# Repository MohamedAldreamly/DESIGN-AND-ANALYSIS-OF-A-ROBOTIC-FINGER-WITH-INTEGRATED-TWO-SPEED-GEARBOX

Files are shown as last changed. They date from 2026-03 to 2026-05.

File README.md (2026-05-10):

# Robotic Finger with Two-Speed Gearbox

## Overview
This project presents the design and analysis of a robotic finger actuated by a compact two-speed gearbox. The system combines mechanical simplicity with efficient motion transmission by using direct coupling instead of traditional tendon-driven mechanisms.

The finger motion is achieved using a dual four-bar linkage system that ensures coordinated movement of the phalanges.

---

## Key Features
- Two-speed gearbox (Speed Mode & Force Mode)
- Direct mechanical coupling (no tendons required)
- Coordinated motion using four-bar linkage mechanisms
- Compact and efficient mechanical design
- Designed for educational and experimental applications

---

## System Description
The system consists of two main subsystems:

### 1. Gearbox
- Multi-stage spur gear system
- Two operating modes:
  - Speed Mode → fast motion
  - Force Mode → high torque output
- Dog clutch mechanism for switching between modes

### 2. Finger Mechanism
- Three phalanges connected by revolute joints
- Motion coordination achieved using two coupled four-bar linkages
- Direct connection between output shaft and first phalanx

---

## Design Process
The project was developed through the following steps:

1. Kinematic analysis of finger motion  
2. Four-bar linkage synthesis  
3. Torque estimation and gearbox design  
4. Gear selection and force calculations  
5. Shaft design (bending + torsion)  
6. CAD modeling using SolidWorks  
7. Motion simulation  
8. Structural validation using FEA  

---

## Analysis & Validation
- Analytical calculations for gears and shafts  
- Finite Element Analysis (FEA) for:
  - Output shaft  
  - Gear teeth  
  - Dog clutch  
- Validation of stress distribution and critical regions  

---

## Key Results
- Output torque achieved: ≈ 1.94 N·m  
- Smooth and coordinated finger motion  
- Good agreement between analytical and FEA results  
- Critical stress concentrations identified and analyzed  

---

## Limitations
- Stress concentration at shaft shoulders  
- Gear tooth root is the most critical region  
- Dog clutch engagement may introduce shock loads  
- No fatigue life analysis (future work)  

---

## Future Improvements
- Fatigue analysis under cyclic loading  
- Optimization of shaft geometry (fillet radius)  
- Improved clutch engagement mechanism  
- Prototype manufacturing and testing  

---

## Tools Used
- SolidWorks (CAD & Motion Analysis)  
- ANSYS (Finite Element Analysis)  
- Engineering calculations (analytical design)  

---

## Author
Mohamed Ayman Aldreamly  
Mechatronics Engineering Student  

---

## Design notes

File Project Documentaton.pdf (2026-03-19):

# DESIGN AND ANALYSIS OF A ROBOTIC FINGER WITH INTEGRATED TWO-SPEED GEARBOX

# Prepared by: Mohamed Ayman Aldreamly

## Courses: Mechanical Design Project Theory of Machine Kinematics

## Supervisor:

me

Alazhar University
Faculty of Engineering
Department of Mechatronics Engineering

March 2026

## Contents

- PROJECT OBJECTIVES AND PLANNING

- Gearbox–Finger Mechanical Coupling
- CAD Design and Motion Analysis
- Gearbox CAD Design
- Finite Element Analysis

8.2 FEA Results and Discussion of the Output Shaft under Combined Torsion and Bending ..56

- Failure Modes Analysis
- Conclusion

# - PROJECT OBJECTIVES AND PLANNING

## 1.1.1 Objectives and Constraints

The objective of this project is to design and analyze a robotic finger mechanism capable of producing coordinated finger flexion using a compact mechanical transmission system.

The robotic finger consists of three rigid phalanges connected through revolute joints. The motion of the finger is generated by a motor and transmitted through a compact gearbox integrated at the base of the finger.

Unlike tendon-driven robotic fingers, the actuation in this design is achieved through direct mechanical coupling between the gearbox output shaft and the first phalanx. The output shaft is oriented perpendicular to the first phalanx and connected using a mechanical screw joint.

The coordinated motion of the remaining phalanges is achieved using two coupled four-bar linkage mechanisms.

The design therefore integrates two main subsystems:

- A two-speed gearbox that provides different torque and speed operating modes.
- A four-bar linkage mechanism that coordinates the motion of the three phalanges.

The main design constraints are:

- Compact mechanical structure suitable for a robotic finger base.
- Smooth coordinated motion between phalanges.
- Sufficient output torque to flex the finger.
- Clear mechanical architecture suitable for educational demonstration.

## 1.1.2 Planning

The project development followed a systematic mechanical design approach consisting of several stages.

The first stage involved defining the motion requirements of the robotic finger and determining representative finger configurations.
The second stage focused on synthesizing a four-bar linkage mechanism capable of reproducing the desired motion of the finger joints.
The third stage involved estimating the torque requirements needed to move the finger mechanism.
The fourth stage consisted of designing a compact gearbox capable of providing two operating modes: high speed motion and high torque operation.
Finally, the gearbox output shaft was integrated directly with the first phalanx using a rigid mechanical connection to transmit rotation to the finger mechanism.

## 1.2 PRELIMINARY DESIGN

The robotic finger system integrates a gearbox actuator with a mechanical linkage mechanism.

The main structural components of the system are:

- Three rigid phalanges
- Revolute joints connecting the phalanges
- Two four-bar linkage mechanisms
- A compact two-speed gearbox
- A direct mechanical connection between the gearbox output shaft and the first phalanx

The gearbox is mounted at the base of the finger, and its output shaft is oriented perpendicular to the first phalanx.

The shaft is rigidly connected to the first phalanx using a screw connection. When the gearbox output shaft rotates, the first phalanx rotates around its base joint.

The motion of the first phalanx drives the four-bar linkage system, which in turn produces coordinated motion of the second and third phalanges.

This configuration simplifies the mechanical architecture and allows the robotic finger to be driven using a single actuator.

## 1.3 PHALANX ANALYSIS

The robotic finger consists of three rigid segments representing the phalanges.

Their lengths are:

Phalanx 1 = 50 mm
Phalanx 2 = 30 mm
Phalanx 3 = 20 mm

The motion of the finger is described by the rotation angles of the three phalanges relative to the base.

Three key configurations were defined to represent the range of motion of the finger:

Case 1 – extended finger
Case 2 – intermediate flexion
Case 3 – highly flexed finger

The position of the finger joints was calculated using planar kinematic relations.

The coordinates of the PIP joint are given by

x₁ = L₁ cos θ₁
y₁ = L₁ sin θ₁

The DIP joint coordinates depend on the cumulative rotation of the first two phalanges.

The fingertip coordinates depend on the cumulative rotation of all three phalanges.

These calculations define the motion trajectory of the finger and are used as input for the four-bar linkage synthesis.

## 1.4 PHALANX ANGLES

## 1.4.1 Defining Angles

To analyze the motion of the robotic finger, three rotational angles were defined corresponding to the rotation of each phalanx relative to its preceding segment.

These angles describe the configuration of the finger and determine the position of the joints during motion.

The angles used in the analysis are:

- θ1 : rotation of Phalanx 1 relative to the base joint
- θ2 : rotation of Phalanx 2 relative to Phalanx 1
- θ3 : rotation of Phalanx 3 relative to Phalanx 2

The cumulative angles used in the kinematic calculations are defined as:

α2 = θ1 + θ2
α3 = θ1 + θ2 + θ3

These angles determine the orientation of each link when calculating the joint positions in the planar coordinate system.

## 1.4.2 Measured Angles

Three reference finger configurations were selected to represent the full motion range of the robotic finger.

These configurations correspond to:

1. Extended finger position
2. Intermediate flexion
3. Highly flexed finger

The measured angles for each configuration are:

Configuration | θ1 θ2 θ3
Case 1 (Extended) | −3° 45° 27°
Case 2 (Intermediate) 39° 71° 43° Case 3 (Flexed) 77° 83° 50°

These values were used as the design targets for the linkage synthesis process.

## 1.4.3 Angles Achieved

After designing the four-bar linkage systems, the mechanism was able to reproduce the desired finger motion across the three configurations.

The synthesized linkage geometry ensures that the second and third phalanges follow the required angular relationship with the first phalanx.

The coordinated motion is achieved through two coupled linkage systems:

- The first four-bar linkage constrains the motion between Phalanx 1 and Phalanx 2.
- The second four-bar linkage transfers motion from Phalanx 2 to Phalanx 3.

This mechanism allows the finger to bend in a coordinated manner similar to the motion of a biological finger.

## 1.4.4 Angle vs. Time

The angular motion of the finger joints depends on the rotational speed of the actuator.

From the gearbox analysis, the motor operates at approximately:

n_motor = 170 rpm

After transmission through the gearbox, the output shaft speed becomes:

- Speed mode
n_out ≈ 56.7 rpm
- Force mode
n_out ≈ 13.3 rpm

As the gearbox output shaft rotates, it drives the rotation of the first phalanx. The motion is then transferred through the four-bar linkages to the remaining phalanges.

This results in a synchronized time-dependent motion of the three finger joints.

# - Robotic Finger Four-Bar Linkage Kinematic Synthesis Report

## 2.1 Objective

The objective of this study is to design a kinematic mechanism for a three‑phalanx robotic finger using two coupled four‑bar linkage systems.

The first linkage controls the motion relationship between Phalanx 1 and Phalanx 2, while the second linkage transfers motion to Phalanx 3.

The design approach follows a three‑position kinematic synthesis method where the finger configuration is defined in three key positions.

## 2.2 Finger Geometry

Phalanx lengths used in the design:

Phalanx 1: 50 mm

Phalanx 2: 30 mm

Phalanx 3: 20 mm

The base of the finger is defined as the coordinate origin (0,0) and the horizontal axis is used as the reference axis for angle measurements.

## 2.3 Reference Configurations

Three finger configurations were defined to represent the range of motion of the robotic finger.

Case 1 (Extended Position)

- θ1 = -3°
- θ2 = 45°
- θ3 = 27°

Case 2 (Intermediate Position)

- θ1 = 39°
- θ2 = 71°
- θ3 = 43°

Case 3 (Highly Flexed Position)

- θ1 = 77°
- θ2 = 83°
- θ3 = 50°

These three configurations were used to synthesize the linkage geometry.

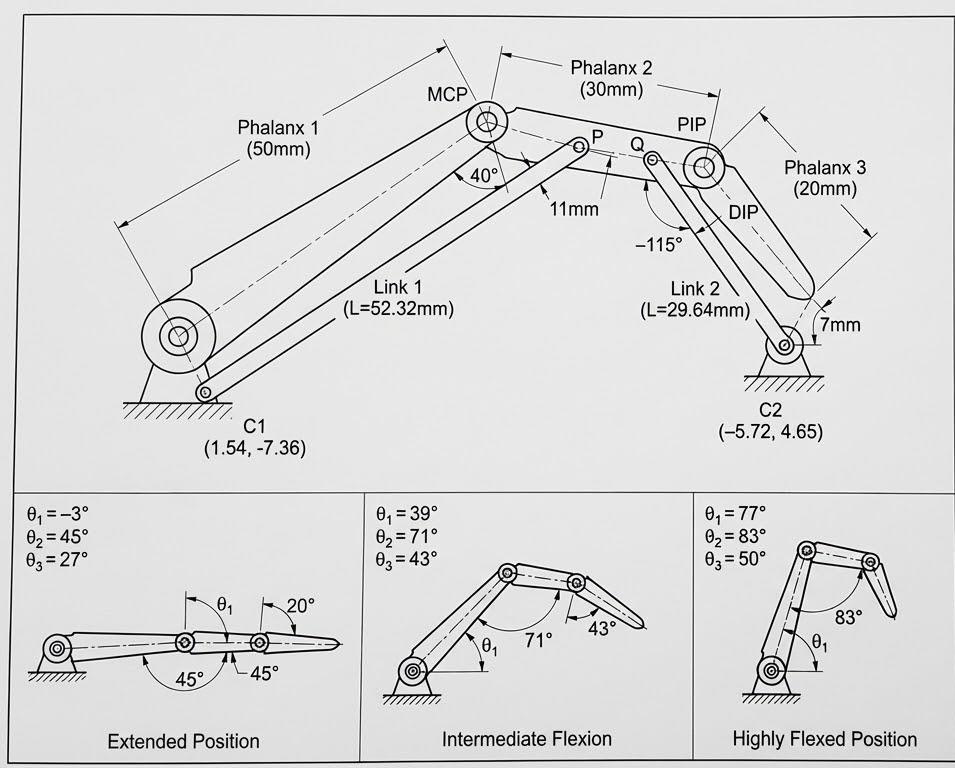
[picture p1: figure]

## 2.4 Joint Coordinate Equations

Position of PIP joint (end of Phalanx 1):

x1 = L1 cos(θ1)

y1 = L1 sin(θ1)

Position of DIP joint (end of Phalanx 2):

α2 = θ1 + θ2

x2 = x1 + L2 cos(α2)

y2 = y1 + L2 sin(α2)

Position of fingertip (end of Phalanx 3):

α3 = θ1 + θ2 + θ3

x3 = x2 + L3 cos(α3)

y3 = y2 + L3 sin(α3)

## 2.5 Calculated Joint Coordinates

Case 1

PIP: (49.93 , -2.62)

DIP: (72.23 , 17.46)

Tip: (79.39 , 36.13)

Case 2

PIP: (38.86 , 31.47)

DIP: (28.60 , 59.66)

Tip: (10.78 , 68.74)

Case 3

PIP: (11.25 , 48.72)

DIP: (-16.94 , 58.98)

Tip: (-34.26 , 48.98)

## 2.6 First Linkage System

The first linkage couples the motion between Phalanx 1 and Phalanx 2.

Selected coupler point on Phalanx 2:

Distance from PIP joint = 11 mm

Local angle = 40°

Coordinates of the coupler point were calculated for the three configurations:

P1 = (51.46 , 8.28)

P2 = (29.33 , 36.97)

P3 = (0.91 , 44.96)

Using perpendicular bisectors of the three points, the center of the circle representing the fixed pivot of the first link was determined:

C1 = (1.54 , -7.36)

The length of the first linkage bar (radius of the circle) was calculated as:

Link 1 Length = 52.32 mm

## 2.7 Second Linkage System

The second linkage transfers motion to Phalanx 3.

Coupling point selection:

Distance from PIP = 7 mm

Angle relative to Phalanx 1 = -115°

Coordinates of the coupling point for the three cases:

Q1 = (46.65 , -8.80)

Q2 = (40.55 , 24.67)

Q3 = (16.76 , 44.41)

After transforming these coordinates into the reference frame of Phalanx 3, the following points were obtained:

Q1' = (-33.68 , 14.47)

Q2' = (-26.53 , 25.74)

Q3' = (-21.91 , 29.47)

The circle passing through these three points defines the fixed pivot location for the second linkage:

C2 = (-5.72 , 4.65)

The corresponding linkage length is:

Link 2 Length = 29.64 mm

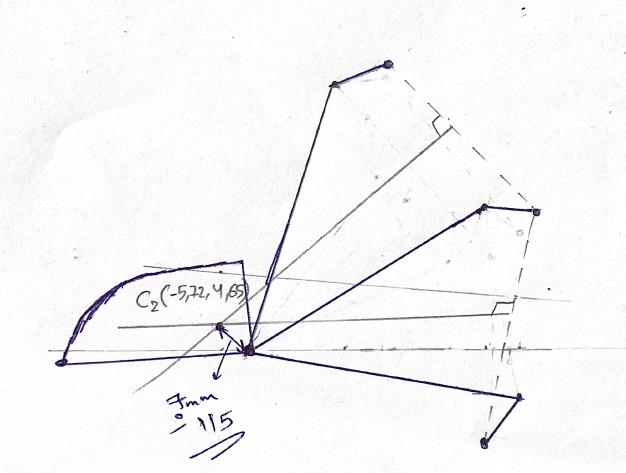
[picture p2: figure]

## 2.8 Motion Transfer Explanation

Motion transfer occurs sequentially through the mechanism:

1. Rotation of Phalanx 1 around the base joint drives the first linkage.
2. The first linkage constrains the motion of Phalanx 2 according to the synthesized geometry.
3. As Phalanx 2 moves, the coupling point near the PIP joint moves along a defined trajectory.
4. This trajectory drives the second linkage system.
5. The second linkage converts this motion into rotation of Phalanx 3 around the DIP joint.

This creates coordinated finger flexion similar to biological fingers.

## 2.9 Final Design Parameters

Phalanx Lengths

- L1 = 50 mm
- L2 = 30 mm
- L3 = 20 mm

Linkage System 1

Coupler point on Phalanx 2: (11 mm , 40°)

Fixed pivot: (1.54 , -7.36)

Link length: 52.32 mm

Linkage System 2

Coupling point: (7 mm , -115°)

Equivalent point on Phalanx 3: (7.37 mm , 141°)

Link length: 29.64 mm

Coupler point selection criteria

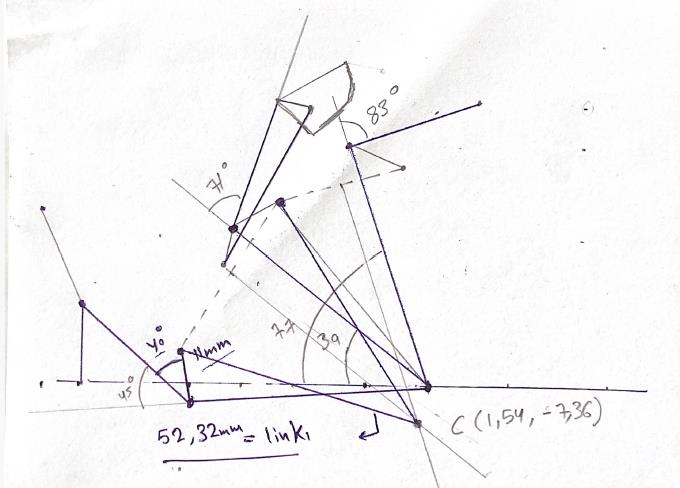
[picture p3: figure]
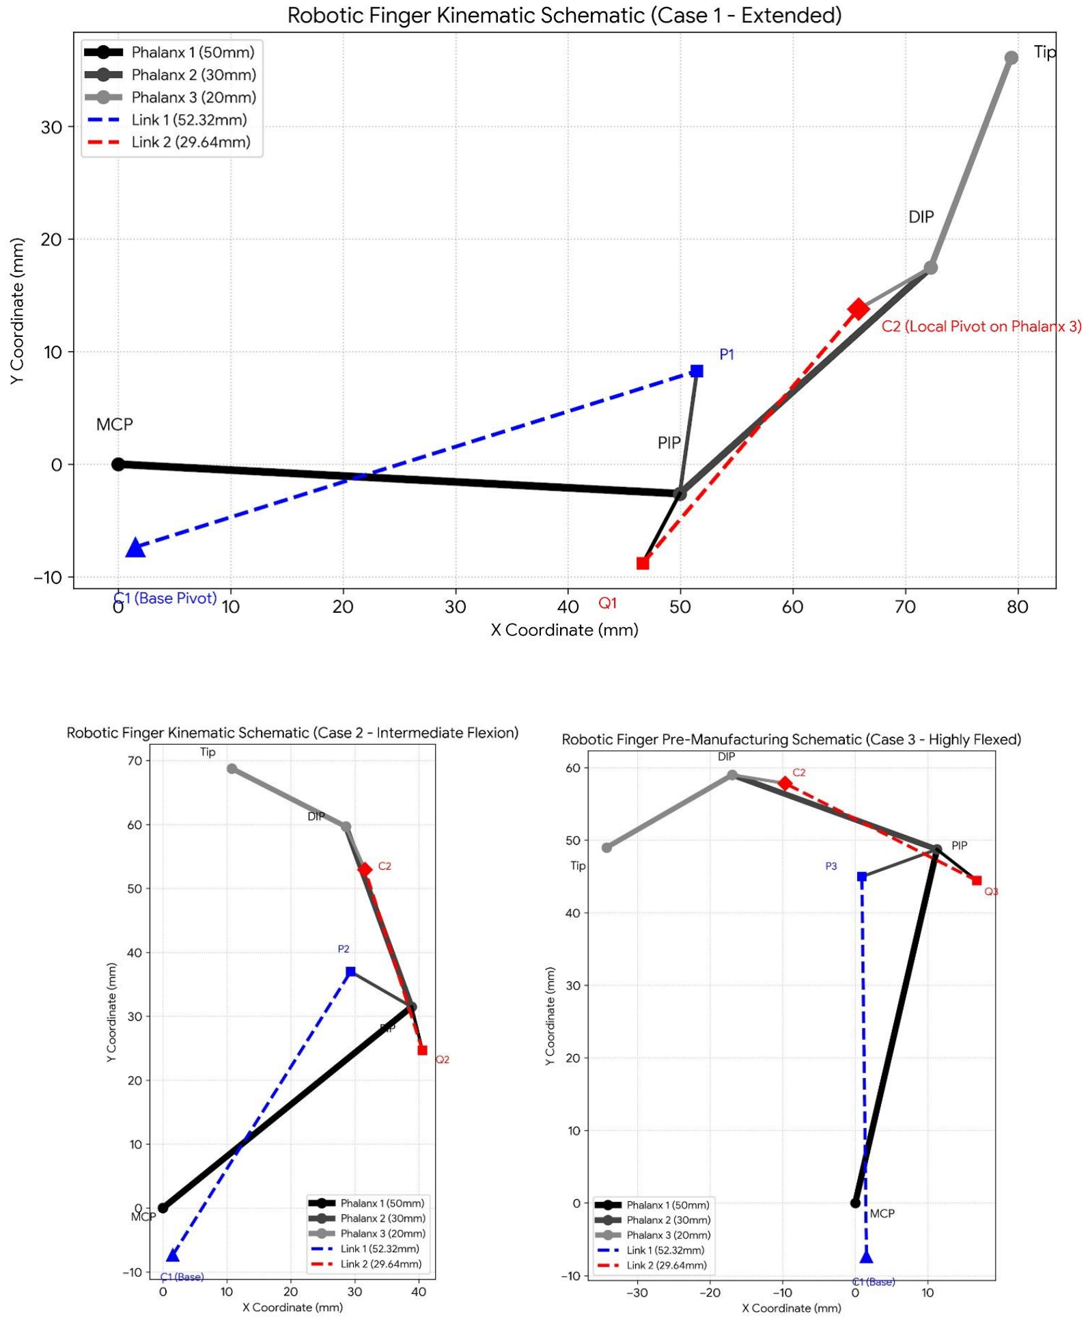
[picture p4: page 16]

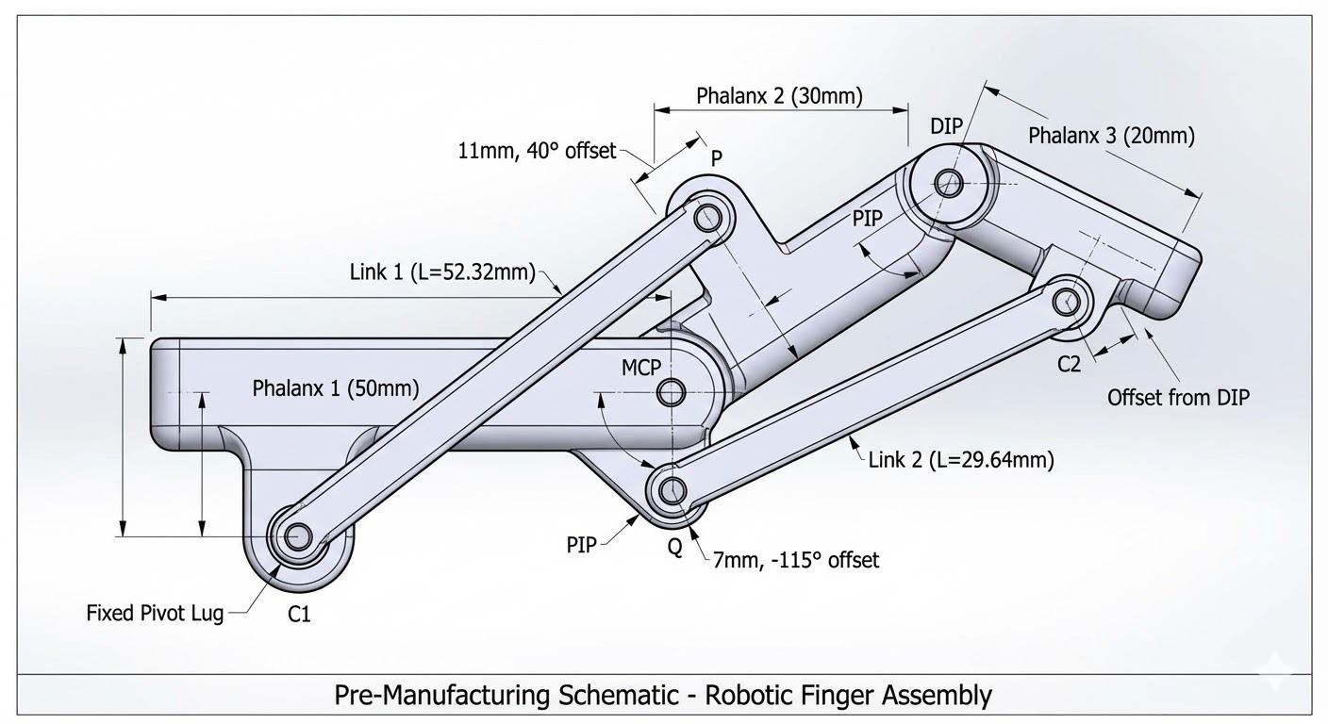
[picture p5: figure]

The coupler points were selected based on three design criteria:

- Normalized distance along the phalanx
0.3L ≤ d ≤ 0.5L0
- Angular placement
The point is placed between
30∘−60∘
relative to the phalanx axis to ensure adequate moment arm.
- Geometric scaling
The dimensions from the reference design were scaled according to the ratio of phalanx lengths between the reference design and the current robotic finger

# - Design and study a gearbox:

## 3.1.1 Important Note Regarding the Report Content

This report includes detailed engineering calculations, numerical compensations, design assumptions, phased verification, and sensitivity and uncertainty analysis.

## 3.1.2 Study Objective

The objective is to design a gearbox integrated into the base of the robotic finger to provide two operating modes:

- Speed Mode: for rapid finger closure before contact with the object.
- Force Mode: for increased torque after contact and improved gripping force.
- Switching between the two modes is achieved via a sliding dog clutch on the output shaft.

## 3.1.3 Basic Design Inputs Used in the Study

Parameter | Value | Note
Required output torque in the critical condition | 1.9 N·m | From finger analysis in near-open configuration
Gear type | Spur gears | For manufacturing and analysis simplicity
Pressure angle | 20° | Standard value
Initial module | 0.5 mm | For compact size
Target static safety factor | 2 | Required by design
System arrangement | Motor → Gears → Dog Clutch → Output Shaft → Tendon Drum | Power transmission chain

## 3.1.4Motor Selection

A DC motor with an internal gearbox and encoder was adopted as the starting design reference because it provides a good balance between size, performance, and cost.

The assumed parameters are:

Property | Value
Operating voltage | 6 V
Operating speed | 170 rpm
Rated torque | 0.196 N·m
Approximate dimensions | 52 × 24 mm
Approximate mass | 96 g

Important note:
These values represent a design baseline. If the motor is changed later, the reduction ratios can easily be recalculated because all equations are written first in symbolic form and then numerically evaluated.

## 3.1.5 Derivation of Required Reduction Ratios

Approximate efficiencies were assumed as:

- Speed path (one gear pair + dog clutch) η_s ≈ 0.90 × 0.95 = 0.855
- Force path (two gear pairs + dog clutch)
η_f ≈ 0.90 × 0.90 × 0.95 = 0.77

The basic relationship between motor torque and output torque is

Tout=η×i×Tm

Where:

- Tout= output torque
- η = total efficiency
- i = reduction ratio
- Tm = motor torque

In Force Mode, we must achieve at least the required torque.

This satisfies the requirement of the project:
in force mode the system reaches approximately 1.94 N·m, slightly higher than the required 1.9 N·m.

The minimum required reduction ratio becomes

iforce,min= Tout,req/(ηforce×Tm) iforce,min=1.9/0.77×0.196
iforce,min=12.58≈12.6

Therefore the selected ratio is

iforce=12.83

For Speed Mode, the ratio must be much smaller to obtain a higher output speed.

Selected value:

ispeed=3.0

This provides clear separation between the functions of the two modes.

## 3.1.6 Performance Summary

Speed Mode

Tout,s=0.196×3.0×0.855=0.503N⋅m nout,s=170/3=56.7rpm

Force Mode

Tout,f=0.196×12.83×0.77=1.94N⋅m nout,f=170/12.83=13.3rpm

Important result:

The force mode produces 1.94 N·m, which is slightly higher than the required 1.9 N·m, providing a small acceptable safety margin.

## 3.2.1 Gear Tooth Selection and Ratio Implementation

Speed Path

Single gear pair:

Pinion
z₁ = 20

Gear
z₂ = 60

is=60/20=3.0

Force Path

Two-stage compound reduction:

Stage 1
z₁ = 20 → z₃ = 70

if1=70/20=3.5

Stage 2
Pinion on intermediate shaft z₄ = 18

Output gear
z₅ = 66

if2=66/18=3.667

Total force ratio:

if=3.5×3.667=12.83

This configuration matches the intended concept:

The motor rotates continuously, the gears remain in mesh, and the dog clutch locks either the speed gear or the force gear to the output shaft.

## 3.2.2 Preliminary Gear Geometry

Module m=0.5mm
Pressure angle =20°

Pitch diameters:

d=m×zd

Gear | z | Pitch diameter
Gear 1 | 20 | 10 mm
Gear 2 | 60 | 30 mm
Gear 3 | 70 | 35 mm
Gear 4 | 18 | 9 mm
Gear 5 | 66 | 33 mm

Center distances:

- Velocity path: (10+30)/2=20mm
- First stage of torque path: (10+35)/2=22.5mm
- Second stage: (9+33)/2=21mm

These values are compact and suitable for integration inside the base of a robotic finger rather than an industrial gearbox.

The following arrangement was proposed:

path | Stage | Number of teeth pinion | Number of teeth gear | i
speed | One stage | 20 | 60 | 3.0
Torque | Stage1 | 20 | 70 | 3.5
Torque | Stage2 | 18 | 66 | 3.667

## 3.2.3 Gear Force Calculations

Equations used:

Ft=2T /d
Fr=Ft tan(ϕ)

With
tan(20°)≈0.364

First Mesh (Force Path)

- Input torque : Tin=0.196 N⋅m
- Pitch diameter : d1=10 mm
- Tangential force : Ft1=39.2 N
- Radial force : Fr1=14.3 N

Torque on Intermediate Shaft

Tint=Tin×i1×η
Tint=0.196×3.5×0.90
Tint=0.617N⋅m

Second Mesh (Force Path)

- d4=9 mm=0.009 m
- Ft2=137.1N
- Fr2=49.9N

The second mesh in force mode is the most critical mesh.

## 3.2.4 Gear Tooth Bending Check (Lewis Equation)

σb=Ft/(b×m×Y)

Critical pinion
z = 18
Y≈0.31

Conclusion:

5 mm is relatively small
10 mm is excellent but increases gearbox size

Selected compromise:

b=8

## 3.2.5 Initial Contact Stress Check

I won't go into full AGMA now, but from an engineering perspective:

- When Lewis bending is acceptable at b=8mm
- With loads here only around 137 N on the most critical mesh

And with the use of small steel gears or a brass/steel combination, contact stress is unlikely to be the first failure; more likely, the most important factors are:

1. Pinion bending
2. Shaft stiffness
3. Dog clutch shock.

Therefore, at this stage, we consider:

- The initial gear design acceptable bending-wise at b=8mm
- and postpone the detailed AGMA contact test until after the final material is installed.
Face width | Stress
5 mm | 176.9 MPa
8 mm | 110.6 MPa
10 mm | 88.5 MPa

## 3.3.1 Shaft Design (Bending + Torsion)

Equivalent torque:

T_e = √(M² + T²)

Shear stress : τ=16Te/πd3

Allowable shear stress assumed : τallow=40 MPa

## 1-( Input Shaft

carries:

- A relatively small torque T=0.196 N·m
- and the first mesh force Ft=39 N and Fr=14 N

Assuming the distance between two bearings is approximately:

L=16 mm

And taking a gear approximately in the middle, the maximum bending moment is approximately:

M_t = F_t L / 4 = 39.2 × 16 / 4 = 156.8 N·mm
M_r = F_r L / 4 = 14.3 × 16 / 4 = 57.2 N·mm M = √(156.8² + 57.2²) = 166.9 N·mm
T = 0.196 N·m = 196 N·mm

equivalent twisting moment:

T_e = √(166.9² + 196²) = 257.4 N·mm

If we take the allowable shear stress for the small solid metal:

τallow=40 MPa

Therefore:

d³ = 16×257.4 / (π×40) = 32.8

d = 3.2 mm

A slightly higher practical diameter was adopted:

d_in = 4 mm

Very convenient and practically safe.

## 2-( Intermediate Shaft

This is the most dangerous because it carries:

- Second-stage torque T=617N·mm
- Relatively large forces

F_t,total = 39.2 + 137.1 = 176.3 N

F_r,total = 14.3 + 49.9 = 64.2 N

bearing span:

L = 20 mm

Therefore:

M_t = 176.3 × 20 / 4 = 881.5 N·mm M_r = 64.2 × 20 / 4 = 321.0 N·mm
M = √(881.5² + 321.0²) = 938.2 N·mm T = 0.617 N·m = 617 N·mm

T_e = √(938.2² + 617²) = 1122.9 N·mm

d³ = 16×1122.9 / (π×40) = 143.0

d = 5.2 mm

Approved:

d_int = 6 mm

This is also excellent because it is close to the pin sizes you have in your finger joints, and therefore does not look strange in terms of the overall size of the project.

## 3-(Output Shaft

The output shaft carries the ultimate torque:

T_out = 1.94 N·m = 1940 N·mm

And with a dog clutch + drum, it will also have bending.

Assuming conservative bending:

M ≈ 500 N·mm

Therefore:

T_e = √(1940² + 500²) = 2003 N·mm

d³ = 16×2003 / (π×40) = 255.0

d = 6.34 mm

Approved:

d_out = 8 mm

This makes perfect sense because:

- It has a dog clutch
- It has system output
- It has maximum torque

## 3.3.4 Final Shaft Diameters

- Input shaf : 4 mm
- Intermediate shaft : 6 mm
- Output shaft : 8 mm

# 3.4Clutch design

## 3.4.1 What exactly is the function of a dog clutch?

In a transmission, there are two paths:

- Speed mode for fast movement
- Force mode for high torque. However, these two paths cannot be operated simultaneously.

Therefore, the function of a dog clutch is:

- To ensure the hub is always connected to the output shaft
- To have an axially sliding sleeve
- When the transmission is in motion, the teeth of the dog clutch engage with the required gear sockets
- This locks the gear to the shaft while the other gear remains free to rotate. This means it doesn't rely on friction like a friction clutch, but rather on positive mechanical locking.

Because:

- It is small in size
- The torque is not very large
- A clear switching between speed and torque modes is required

## 3.4.2 What torque should a dog clutch withstand?

From your finger analysis:

- The critical near-open state
- The gearbox should provide approximately 1.9 N·m at the output.

In previous calculations, we approximately arrived at:

Tout ≈ 1.94 N/cdotpm

However, we don't design the dog clutch solely at its nominal value because the engagement involves:

- Shock
- Improper load distribution
- The possibility of not all teeth engaging equally

Since the coil itself requires a minimum safety factor of 2, a good design value would be:

Tclutch, design = 2 × 1.94 = 3.88 N/cdotpm

This is rounded to:

Tclutch, design = 4 N/cdotpm

This is an excellent figure for analysis.

## 3.4.3 Choosing the Initial Dog Clutch Shape

Since your gearbox is small and centrally located on the output shaft, the best initial options are:

- 4 dogs
- Quadruple symmetry
- Axial sliding sleeve
- Dog faces with a simple chamfer for easier entry
- Central hub on the output shaft
- Gear pockets on either side of the sleeve or on the two gears themselves

Reason for choosing 4 dogs:

- Simpler to manufacture than 6 or 8 dogs
- Provides good balance
- Suitable for the shaft size we chose (8mm)
- Very easy to draw

## 3.4.4 Suitable Initial Dimensions for the Dog Clutch

Since our initial output shaft is:

dout=8 mm

Let's take realistic initial dimensions:

- Hub inner diameter = 8 mm
- Hub outer diameter/sleeve approximately = 14 to 16 mm
- Average torque transmission radius:

R m≈ 8 mm

- Number of teeth : N=4
- Axial tooth width : b=2.5 mm
- Peripheral tooth thickness : t=3 mm
- Effective engagement depth : h=2.5 mm

These dimensions make perfect sense with a small gearbox inside the base of the finger.

## 3.4.5 The peripheral force transmitted by the dog clutch

The basic relationship:

T=Ft ×rm

Therefore :

Ft=T/rm

Using the design torque:

T=4 N\cdotpm

rm=8 mm=0.008 m

We get:

Ft=40.008=500 N

Therefore, the total peripheral force that the clutch must transmit is:

Ft=500 N

## 3.4.6How is the load distributed across the dogs?

Here's a very important point in any clutch design:

Don't assume that all teeth share the load equally.

Even though you have 4 dogs, in reality, due to:

- clearances
- manufacturing tolerance
- slight misalignment, the initial load is often only distributed across two dogs.

So, let's consider :neff=2

Therefore, the power over every dog is effective:

Fdog=500/2=250 N

This is a conservative and excellent hypothesis in the report.

## 3.4.7 Surface pressure testing (Bearing/Crushing) on the dog face

Load area per dog:

Ab=b×h
Ab=2.5×2.5=6.25 mm2

Therefore, surface loading stress:

σb=Fdog/Ab=250/6.25=40 MPa

Therefore :

σbearing≈40 MP

This is a very good figure if the dog clutch is made of:

- steel
- or even simple hardened steel/alloy steel. It's generally quite acceptable.

## 3.4.8 Examination of the sternum on the dog

Now we examine the tooth itself on the sternum.

Approximate sternum area:As=t×b

As=3×2.5=7.5 mm2

Shear stress: τ=Fdog/As=250/7.5=33.3 MPa

Therefore :

τdog≈33 MPa

This is also a very good starting point for a suitable metallic material.

## 3.4.9 What does this result mean in practice?

- This result is excellent because it means:
- The dog clutch, with the initial dimensions chosen, is capable of withstanding the design torque.
- The compression and shear are not dangerously high.
- Therefore, the dog itself is not usually the first point of weakness.

Rather, the real danger lies in:

- Engagement shock
- Speed difference between the two parts
- Poor timing during engagement.

This s very important because it guides us to the next correct design point.

## 3.4.10 Axial Engagement Force

To ensure smooth dog clutch engagement, we often add a lead-in chamfer at the edges. Assume an approximate chamfer angle:

α=15∘

When a peripheral load is present, an axial component arises that is related to the angle of the surface. Approximately:

Fa=Ft tanα

Using the nominal power during normal operation at the output, and not the full safety torque, we take:

Ft=1.94/0.008=242.5 N

e: Therefor

Fa=242.5tan15∘
Fa=242.5×0.268≈65 N

Therefore, the axial force resulting from the inclined surface can reach approximately:

Fa≈65 N

This is a very important result.

What does it mean?

It means that:

If you attempt to engage under a high load, you will need considerable shifting force.

This may result in:

- Difficulty engaging
- Rebound
- Shock
- Rapid edge wear

Conclusion: Engaging should occur under a low load or after reducing speed to minimize shock.

## 3.4.11 Sleeve Length and Travel Distance

Because you have two positions, the sliding sleeve needs three:

- Engaged with the speed gear
- Neutral
- Engaged with the torque gear

Therefore, the axial travel distance should be approximately:s≈h+c

Where :

- h Interlocking depth
- c clearance safety

If we take :

- h=2.5 mm
- clearance = 0.5 mm

The journey is one-way: s=3 mm

So from the center outwards in every direction:

s≈3 mm

The overall journey between the two situations:

stotal≈6 mm

This is an excellent, small, and suitable number within a small housing.

## 3.4.12 Clearances and Manufacturing

Because the project has a condition:

- low backlash
- smooth engagement
- practical assembly

The following instructions should be followed:

- Radial fit: Slightly sliding between the sleeve and hub
- Small side clearance between the dogs and pockets
- Chamfer at the edges: 10 to 15∘
- Root fillet: Good for reducing stress concentration
- Do not make the tooth too sharp

# 3.5 Bearing Study

## 3.5.1 How many bearings are there per shaft?

The correct order in this gearbox is:

- Input shaft: 2
- Intermediate shaft: 2
- Output shaft: 2

So, the total number of bearings is:

6 bearings

Reason:

- Each shaft carries gear forces
- You must prevent tilting and swerving
- The dog clutch on the output shaft requires precise alignment
- Having only one bearing per shaft is not mechanically sufficient

## 3.5.2 Input shaft bearings

On the input shaft, we had the first mesh:

- Ft=39.2N
- Fr=14.3N

If the gear is positioned between two bearings approximately in the middle, then each bearing carries half the load in each direction:

Rt=39.22=19.6 N
Rr=14.32=7.15 N

The result on each bearing:

R=19.62+7.152≈20.9N

Therefore:

Each bearing on the input shaft carries approximately 21 N

## 3.5.3 Intermediate shaft bearings

This shaft carries:

- The gear from the first stage
- The pinion from the second stage. Therefore, it carries the combined loads of mesh 1 and mesh 2. We have:

From mesh 1

- Ft1=39.2N
- Fr1=14.3N

From mesh 2

- Ft2=137.1N
- Fr2=49.9N

Approximate total:

Ft,total=39.2+137.1=176.3N
Fr,total=14.3+49.9=64.2 N

Assuming an initial convergent distribution between two bearings:

Rt=176.3/2=88.15 N
Rr=64.2/2=32.1 N

The result on each bearing:

R=88.152+32.12≈93.8 N

Therefore:

Each bearing on the intermediate shaft carries approximately 94 N

## 3.5.4 Output shaft bearings

On the output shaft, you have the final gear load from force mode:

Ft=137.1N
Fr=49.9N

If we consider only the load of the gear:

Rt=68.55 N
Rr=24.95 N

The result:

R=68.552+24.952≈72.9 N

Therefore:

Each bearing on the output shaft carries approximately 73 N.

## 3.5.5 Which shaft is the most sensitive?

The most accurate answer from an engineering perspective is:

From a gear loading perspective only, the most sensitive is the intermediate shaft because it:

- Carries the first and second meshes
- Experiences the highest bending force from the gears
- Has a small pinion in the second stage, which is the most critical gearing element.

However, from the perspective of the entire system, if we consider:

- Gear load
- Dog clutch
- Tendon drum load
- Highest torque, then the most sensitive shaft becomes the output shaft because it:
- Carries the highest torque
- Has a dog clutch
- Has the tendon tension
- Any misalignment directly affects the engagement and tendon tension.

## 3.5.6 Should we use flanged miniature bearings or plain bushings?

My final choice for this project is:

Flanged miniature ball bearings, not plain bushings.

Why?

Because the project system includes:

- Spur gears
- Dog clutch
- Small shafts
- The need for good alignment
- Low backlash
- Low friction
- Smooth shifting. Plain bushings have the following drawbacks:
- Higher friction
- Faster wear
- Lower axial accuracy and angle
- Higher probability of shaft play
- Negatively affects dog clutch engagement. Flanged miniature bearings offer:
- Easier axial mounting within the housing
- Better alignment
- Less friction
- Smoother rotation
- Very suitable for compact gearboxes

## 3.5.7 Proposed Final Distribution

Input shaft

- 2 flanged miniature ball bearings
- Because the load is relatively small, but precision is required

Intermediate shaft

- 2 flanged miniature ball bearings
- Because it carries the highest actual gear reaction

Output shaft

2 flanged miniature ball bearings

This is almost mandatory due to:

- dog clutch
- tendon drum
- higher torque
- the need for excellent alignment

# 3.6 Sensitivity and uncertainty analysis

Engineering sensitivity analysis was adopted instead of purely statistical probability calculations.

## 3.6.1 Sensitivity of output torque to changes in motor torque

If the engine torque changes by ±10%:

T_m,low = 0.176 N·m
T_m,high = 0.216 N·m

T_out,low = 0.77 × 12.83 × 0.176 = 1.74 N·m
T_out,high = 0.77 × 12.83 × 0.216 = 2.13 N·m

Result: The design is relatively sensitive to motor torque; any significant drop in motor torque may cause the output to fall below 1.9 N·m.

## 3.6.2 Sensitivity of output torque to efficiency

η_low = 0.72, η_high = 0.82

T_out(η_low) = 0.72 × 12.83 × 0.196 = 1.81 N·m

T_out(η_high) = 0.82 × 12.83 × 0.196 = 2.06 N·m

Conclusion: Mechanical losses are significant, so attention must be paid to lubrication, manufacturing precision, and bearing quality.

## 3.6.3 Stress sensitivity of gear face width

σ_b ∝ 1/b

Therefore, increasing b from 5 mm to 8 mm reduced the stress from 176.9 MPa to 110.6 MPa, a reduction of approximately 37.5%.

Conclusion: Face width is one of the most influential variables and an effective design tool before resorting to increasing the module.

# - Gearbox Architecture & Power Transmission

The gearbox design relies on a compact spatial architecture to minimize the occupied space within the robotic finger's base. The system consists of three parallel shafts, all supported by a total of six flanged miniature ball bearings (two bearings per shaft) to ensure high precision, minimize friction, and maintain accurate gear alignment during operation .

The mechanism for coupling the shafts and gears, as well as transmitting power, is achieved through two separate kinematic paths (a speed path and a force path), following this mechanical arrangement :

# 4.1 Shafts and Gears Layout:

- Input Shaft: With a diameter of 4 mm, it is directly connected to the motor and rotates continuously. Two gears are permanently fixed to it to act as the primary motion sources: the speed path input pinion (z_1=20) and the force path input pinion (z_3=20) .
- Intermediate Shaft: With a diameter of 6 mm, it is used exclusively for the force path. This shaft receives motion from the input shaft via a larger gear (z_4=70), and transmits it—after amplifying the torque—through a smaller pinion mounted on it (z_5=18).
- Output Shaft: With a diameter of 8 mm, it carries the two final gears: the speed path gear ($z_2=60) and the force path gear (z_6=66). The core feature of this design is that these two gears are free-spinning around the output shaft; meaning they do not directly transmit motion to it in the neutral position.

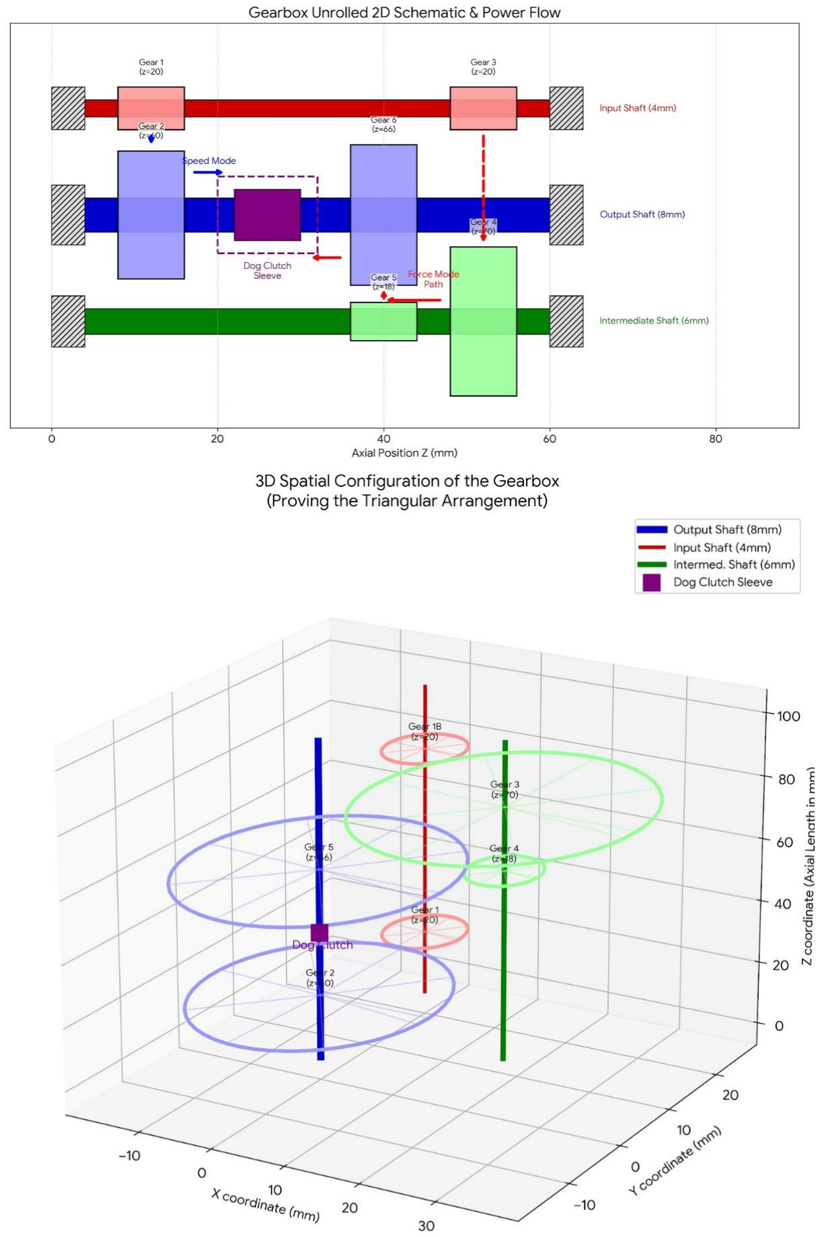
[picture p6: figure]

# 4.2 Dog Clutch Mechanism and Path Selection

To couple the motion from the free-spinning gears to the output shaft, a compact 4-dog clutch is employed, centered between the two final gears . The clutch consists of a hub that is mechanically fixed to the output shaft, and a sliding sleeve that moves axially along the shaft .

- In Speed Mode: The sleeve slides axially to positively mechanically lock its teeth with the recesses of the speed gear ($z=60$) . This locks the gear to the output shaft, transmitting rotation at a speed of 56.7 rpm for rapid finger closure.
- In Force Mode: Upon contact with an object, the sleeve slides in the opposite direction to engage with the force gear ($z=66$) . This disengages the speed path and transmits a high torque of approximately 1.94 N·m to ensure a firm gripping force .

# - Gearbox–Finger Mechanical Coupling

# 5.1 System Integration Concept

To simplify the mechanical architecture of the robotic finger, the gearbox output shaft is directly coupled to the first phalanx of the finger. This design eliminates the need for a tendon transmission system and allows the actuator to drive the finger mechanism through direct rotational motion.

The gearbox is mounted at the base of the finger structure. The output shaft of the gearbox is oriented perpendicular to the first phalanx and aligned with the rotational axis of the base joint.

This configuration allows the gearbox output shaft to act simultaneously as:

- the actuation shaft, transmitting torque from the gearbox
- the rotational joint axis of the first phalanx

As a result, when the gearbox output shaft rotates, the first phalanx rotates around the base joint.

# 5.2 Mechanical Coupling Method

The mechanical connection between the gearbox output shaft and the first phalanx is achieved through a rigid coupling element.

The output shaft is inserted into a cylindrical hub mounted on the first phalanx. The hub is fixed to the shaft using a set screw or bolt, ensuring reliable torque transmission between the shaft and the finger segment.

The hub itself is attached to the first phalanx using small mounting screws. This arrangement allows secure mechanical coupling while maintaining ease of assembly and disassembly.

The selected diameter of the gearbox output shaft is:

d = 8 mm

which provides sufficient torsional strength to transmit the required actuation torque.

# 5.3 Motion Transmission Through the Finger

The motion transfer within the robotic finger occurs sequentially through the mechanism.

1. The motor generates rotational motion.
2. The gearbox modifies the speed and torque according to the selected gear ratio.
3. The gearbox output shaft rotates.
4. The output shaft rotates the first phalanx directly around the base joint.
5. The motion of the first phalanx drives the first four-bar linkage.
6. The first linkage constrains the motion of the second phalanx.

# 5.4 Advantages of the Direct Coupling Design

The direct coupling between the gearbox output shaft and the first phalanx offers several advantages for the robotic finger design:

- Mechanical simplicity, since no tendon or pulley system is required.
- Improved structural rigidity due to direct torque transmission.
- Reduced mechanical losses compared to tendon-driven mechanisms.
- Ease of assembly and maintenance, which is beneficial for educational and experimental purposes.

Additionally, this configuration allows the gearbox to be easily integrated into the base of the finger while maintaining a compact mechanical structure.

# - CAD Design and Motion Analysis

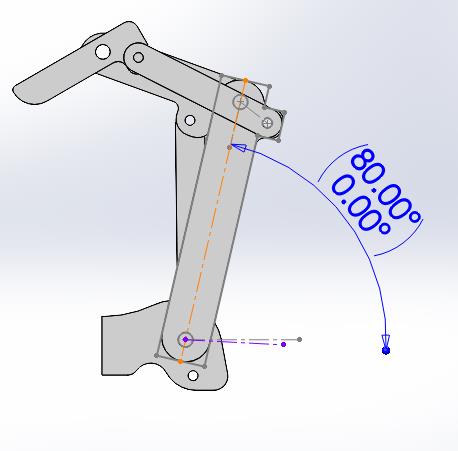
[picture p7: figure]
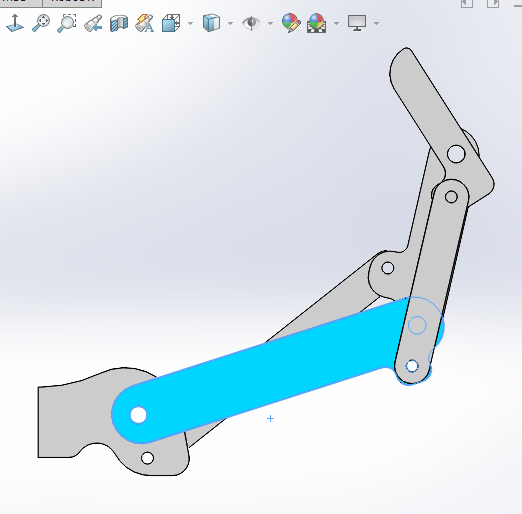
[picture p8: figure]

# 6.1 CAD Modeling of the Robotic Finger

The robotic finger mechanism was modeled using SolidWorks based on the kinematic synthesis results obtained in the previous section. The design consists of three rigid phalanges connected through revolute joints, forming a multi-link mechanism that enables coordinated finger motion.

The phalanges were defined with the following lengths:

- Phalanx 1: 50 mm
- Phalanx 2: 30 mm
- Phalanx 3: 20 mm

Two linkage elements were incorporated to control the motion:

- Link 1: 52.32 mm
- Link 2: 29.64 mm

Key pivot points, including the base pivot (C1), intermediate joint (Q1), and distal connection point (C2), were positioned according to the kinematic design to ensure proper motion transmission.

All components were assembled using revolute (pin) joints implemented through concentric mates in SolidWorks, allowing rotational motion between connected parts while maintaining geometric constraints.

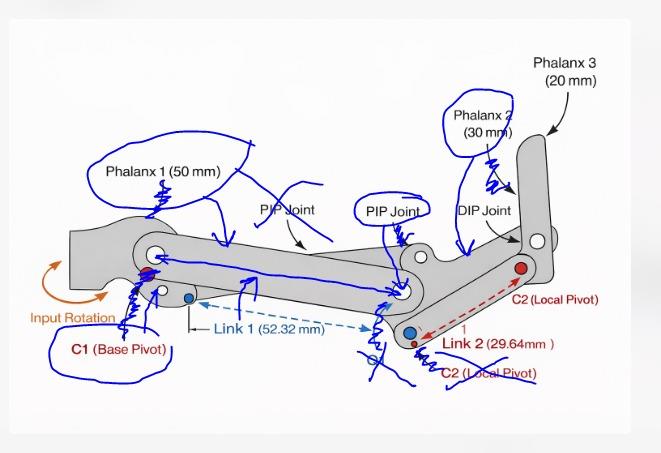
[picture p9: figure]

# 6.2 Motion Study Setup

A motion study was conducted using the SolidWorks Motion Analysis tool to evaluate the dynamic behavior of the mechanism. A rotary motor was applied at the base joint (MCP) to drive the first phalanx, representing the input actuation of the system.

The simulation was performed over a duration of 4 seconds with a constant angular input. The motion of the remaining phalanges was generated automatically through the linkage system, reflecting the coupled kinematic behavior of the mechanism.

# 6.3 Kinematic Results

To assess the performance of the mechanism, angular displacement, angular velocity, and angular acceleration were extracted for a selected phalanx during the simulation.

## 6.3.1 Angular Displacement

The angular displacement curve shows a continuous variation over time, indicating smooth rotational motion of the phalanx. A discontinuity observed near the end of the simulation corresponds to angular wrapping (±180° transition) rather than a physical instability in the mechanism.

## 6.3.2 Angular Velocity

The angular velocity profile demonstrates a gradual increase followed by a smooth decrease, indicating stable motion transmission without abrupt changes. This behavior confirms that the mechanism does not experience sudden jerks or irregular motion during operation.

## 6.3.3 Angular Acceleration

The acceleration curve exhibits a single peak during the transition phase, corresponding to the rapid change in motion as the finger flexes. However, no excessive spikes or oscillations are observed, which indicates that the system operates within acceptable dynamic limits.

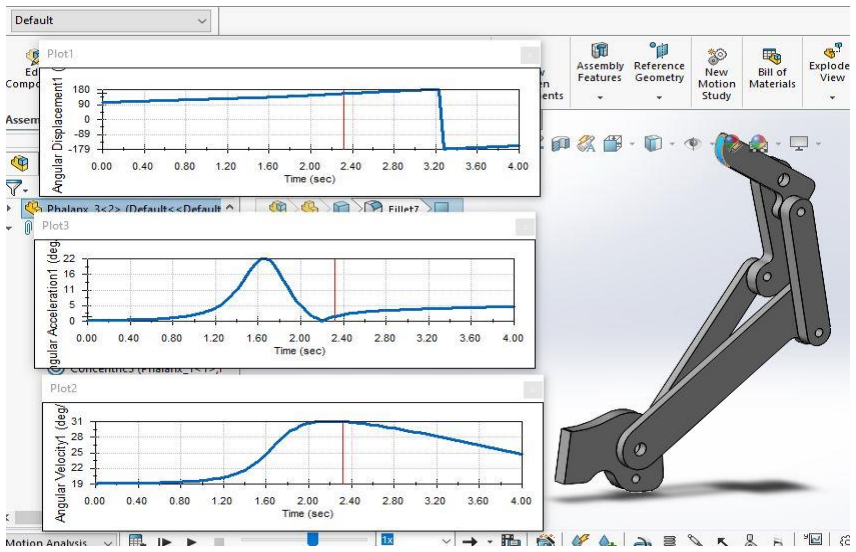
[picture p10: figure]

## 6.4 Motion Smoothness Evaluation

The obtained results confirm that the robotic finger mechanism achieves smooth and coordinated motion. The absence of discontinuities in velocity and the controlled behavior of acceleration indicate that the linkage design successfully synchronizes the movement of all phalanges.

Additionally, the simulation visually confirms that the mechanism transitions between extended and flexed configurations without mechanical interference or instability.

## 6.5 Conclusion

The SolidWorks CAD model accurately represents the kinematic design of the robotic finger. The motion analysis results validate the effectiveness of the linkage system in producing smooth, coordinated motion. Therefore, the proposed design is suitable for further development and potential implementation in robotic applications.

The CAD-based motion analysis confirmed that the motion is smooth, with continuous angular displacement and no abrupt changes in velocity or acceleration. This indicates good dynamic behavior. However, the simulation assumes ideal joints without friction, clearance, or backlash. In a real system, these factors may introduce deviations from the predicted motion and reduce overall accuracy.

# - Gearbox CAD Design

# 7.1 Design Objective

The primary objective of the gearbox design is to transmit motion from the actuator to the robotic finger while achieving the required torque and speed characteristics. The gearbox was designed to provide a compact, efficient transmission system that fits within the spatial constraints of the overall mechanism.

# 7.2 Overall Configuration

The developed gearbox consists of three shafts and a set of five gears arranged to achieve the desired transmission ratio. The gear distribution across the shafts was determined based on the theoretical design calculations, ensuring proper motion transfer between stages.

Each shaft carries one or more gears depending on its role in the transmission system. The arrangement follows a multi-stage configuration, allowing gradual modification of speed and torque through successive gear engagements.

# 7.3 Gear and Shaft Arrangement

The gears were positioned on their respective shafts according to the calculated center distances and gear ratios. This ensured proper meshing conditions and smooth engagement between mating gears.

The shaft layout was carefully designed to:

- Maintain accurate alignment between meshing gears
- Avoid geometric interference between components
- Ensure structural stability of the rotating elements

Additionally, the relative positioning of large and small gears was optimized to achieve a compact and balanced configuration.

# 7.4 Integration of Supporting Components

The gearbox assembly includes essential supporting elements such as bearings and a clutching mechanism. Bearings were incorporated to support the shafts and maintain their alignment during operation, while the clutch mechanism enables switching between operating modes.

The placement of these components was considered during the design phase to ensure:

- Proper load distribution
- Ease of assembly
- Compatibility with the overall system

# 7.5 CAD Modeling and Assembly Verification

The gearbox was fully modeled and assembled in SolidWorks to translate the theoretical design into a practical mechanical system. The CAD environment allowed verification of:

- Gear alignment and meshing conditions
- Shaft positioning and spacing
- Overall assembly coherence

Through the three-dimensional model, the feasibility of the design was confirmed, ensuring that all components fit together correctly without interference.

# 7.6 Visualization and Representation

To improve clarity and understanding of the design, multiple visualization techniques were used, including:

- Isometric assembly views
- Exploded views showing component order
- Sectional views illustrating the internal structure

These representations provide a clear insight into the internal configuration of the gearbox and facilitate better communication of the design.

# 7.7 Design Validation

The CAD model served as a validation step between the theoretical calculations and the physical implementation. It confirmed that:

- The designed transmission system is geometrically feasible
- The components can be assembled practically
- The overall layout satisfies the design constraints

# 7.8 Figure Caption

SolidWorks model of the gearbox assembly illustrating the arrangement of shafts, gears, and supporting components.

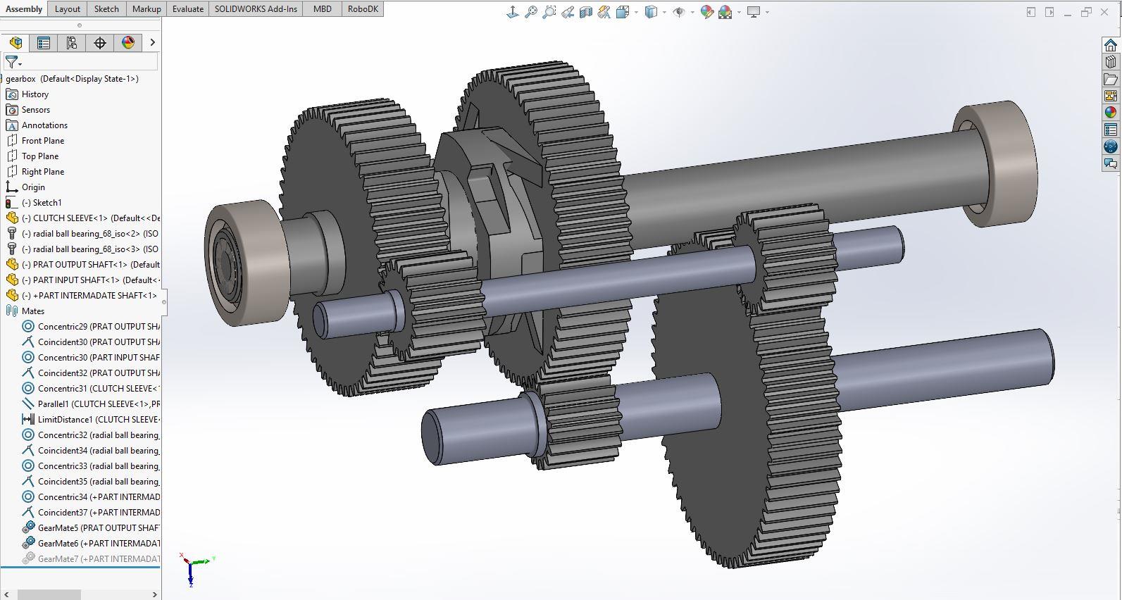
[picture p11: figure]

# - Finite Element Analysis

## 8.1.1 FEA Results and Discussion of the Output Shaft under Torsion Only

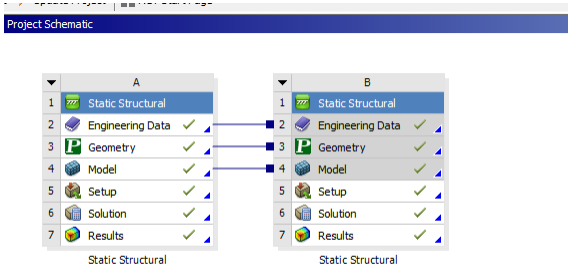
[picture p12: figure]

## Analysis Setup and Boundary Conditions

A static structural analysis was performed on the output shaft to evaluate its structural behavior under torsional loading. The purpose of this analysis is to validate the analytical design and assess the stress distribution along the shaft, particularly in critical regions such as shoulders and diameter transitions.

## Geometry

The analysis was carried out on the output shaft only, without including the full gearbox assembly. This simplification allows for an efficient and focused evaluation of the shaft under its primary loading condition.

## Material

The shaft material was defined as structural steel, with standard mechanical properties (Young’s modulus, Poisson’s ratio, and yield strength).

## Boundary Conditions

To ensure a stable and physically meaningful solution, the following boundary conditions were applied:

- A Fixed Support was applied on the internal bearing seat of the output shaft. This constraint prevents all translational and rotational degrees of freedom at that location and represents the support provided by the bearing inside the gearbox.
- A Moment load was applied on the outer end of the shaft, corresponding to the interface with the robotic finger.
The applied torque was:

T=1.94 N.m

This value represents the output torque in the force mode, as obtained from the design calculations.

## Mesh

A refined mesh was generated, with additional refinement in regions of geometric discontinuity such as shoulders and fillets to accurately capture stress concentration effects.

## 8.1.2 Analytical Calculation

For a solid circular shaft subjected to pure torsion, the maximum shear stress is given by:

τnom=16T/πd3

Substituting:

T=1940N.mm,d=8mm
τnom=16(1940) /π(8)3 =19.3MPa

This value represents the nominal shear stress in the uniform region of the shaft.

## 8.1.3 FEA Results

The shear stress in the uniform cylindrical section of the shaft was approximately:

τ≈18.9 MPa

The maximum shear stress occurred at the shoulder region, reaching:

τmax≈42.6 MPa

The deformation pattern indicated a pure torsional behavior, with no significant bending observed in this loading case.

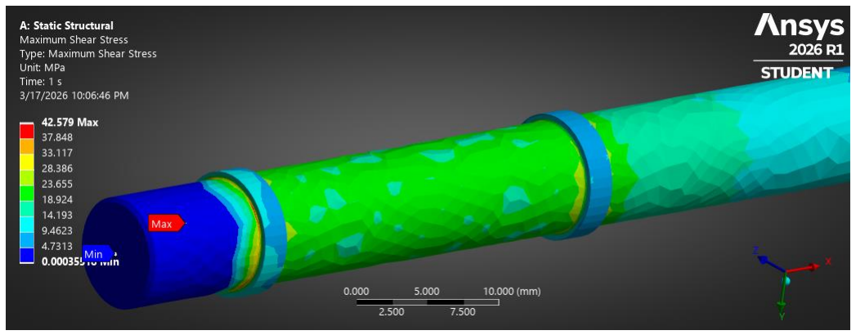
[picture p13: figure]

## 8.1.4 Discussion

The FEA results show excellent agreement with the analytical calculations. The nominal shear stress obtained from theory (19.3 MPa) closely matches the FEA result (≈18.9 MPa) in the uniform shaft region. This confirms the correctness of the applied boundary conditions and loading.

However, a significant increase in stress was observed at the shoulder, where the shaft diameter changes. This increase is due to torsional stress concentration caused by geometric discontinuity.

The stress concentration factor can be estimated as:

Kts=τnom/τmax=19.342.6≈2.2

This value is consistent with typical stress concentration factors for stepped shafts under torsion.

It is important to note that such stress concentration effects are not captured by analytical calculations, which assume a uniform shaft. Therefore, the FEA provides a more realistic representation of the stress distribution.

## 8.1.5 Design Validation

From the design calculations, the required shaft diameter was approximately:

drequired≈6.34 mm

However, a diameter of 8 mm was selected in the final design to ensure safety and manufacturability.

The FEA results confirm that:

- The shaft operates within a safe stress range
- The design is conservative
- The most critical region is the shoulder, not the main shaft body

## 8.1.6 Conclusion

The output shaft demonstrates safe and reliable performance under the applied torsional load of 1.94 N·m. The analytical and numerical results are in strong agreement in the uniform shaft region, validating the design approach.

The FEA analysis highlights the importance of geometric features, particularly the shoulder, as the governing location for stress concentration. Overall, the selected shaft diameter of 8 mm provides an adequate safety margin for the intended application.

# 8.2 FEA Results and Discussion of the Output Shaft under Combined Torsion and Bending

A second static structural analysis was performed on the output shaft under combined torsional and bending loading in order to represent a more realistic operating condition. The output shaft was selected for detailed investigation because it carries the highest transmitted torque in the system, incorporates the dog clutch, and acts as the direct output member coupled to the first phalanx. According to the analytical design, the output shaft in force mode transmits approximately 1.94 N.m, and a conservative bending moment of about 500 N.m was assumed in the shaft sizing stage. This led to an equivalent torque of 2003 N.m, from which the required shaft diameter was estimated as 6.34 mm. The final adopted diameter was increased to 8 mm, providing an intentionally conservative design margin.

## 8.2.1 Boundary Conditions

In this study, the shaft was modeled as an individual solid part. A fixed support was applied at the inner bearing seat to prevent rigid body motion, while the external end of the shaft was loaded by the design output torque. In addition, a transverse force was applied to generate the conservative bending moment considered in the analytical design. This setup represents the combined effect of torque transmission and external bending caused by the output coupling and shaft-mounted components.

## 8.2.2 Shear Stress Evaluation

The finite element results showed that the maximum shear stress reached approximately

### 44.5 MPa, with the peak occurring locally at the shoulder region. This value is slightly

higher than the allowable shear stress adopted in the preliminary shaft design, which was taken as τallow=40 MPa. However, this exceedance is localized and is caused by geometric stress concentration at the shoulder rather than by excessive stress along the full shaft length. Since the analytical design equations assume a uniform circular shaft without geometric discontinuities, they do not capture the local amplification of stress caused by shoulders and fillets. Therefore, the difference between the analytical value and the FEA peak is expected and physically meaningful rather than a sign of incorrect design.

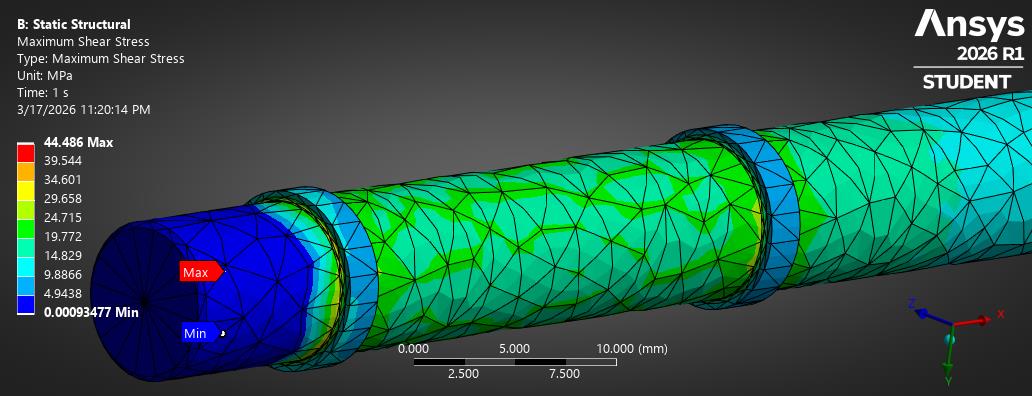
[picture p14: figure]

## Equivalent Stress Evaluation

The equivalent (von Mises) stress was estimated analytically for the straight portion of the output shaft under combined torsion and bending using:

σvm = sqr ))σb(2+)3τ(2(

where the bending stress is:σb=32M/πd3

and the torsional shear stress is:

τ=16T/πd3

Using the design values from the report, =1.94N⋅m=1940N⋅mm, M≈500 N⋅mm, and d=8 mm, the calculated stresses are:

τ≈19.3 MPa
σb≈9.95 MPa

Thus, the nominal equivalent stress becomes:

σvm= sqr((9.95)2+3(19.3)2)≈34.9 MPa

The FEA result showed a maximum equivalent stress of approximately 77.1 MPa. This value is higher than the analytical result because the analytical calculation represents the nominal stress in the uniform shaft section Meanwhile, the FEA detected stress concentration at the shoulder area. Therefore, the analytical result and the numerical result are consistent, with the FEA revealing the local stress amplification caused by the geometric discontinuity.

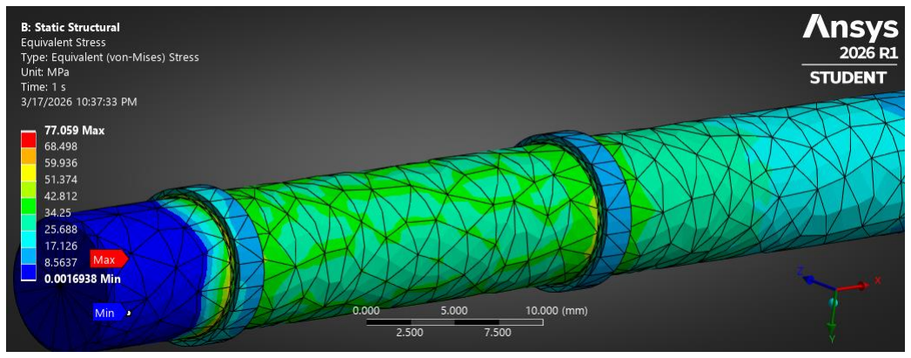
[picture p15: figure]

## 8.2.3 Interpretation

The combined results show that the selected output shaft diameter remains acceptable for the intended application. The analytical method used in the report was appropriate for initial sizing, while the FEA provided a more realistic representation of the stress field, especially near geometric discontinuities. The shoulder is clearly the most critical local region, and its stress level is governed by stress concentration rather than by insufficient global shaft diameter. Consequently, the output shaft design cannot be considered poor or unsafe solely because the local maximum shear stress slightly exceeds the assumed allowable design shear stress. Rather, the results indicate that the shaft is generally safe, while the shoulder is the critical location that may benefit from local geometric improvement, such as increasing the fillet radius or smoothing the diameter transition.

## 8.2.4 Conclusion

The second FEA study confirms that the output shaft behaves safely under combined torsion and bending. Although the maximum local shear stress at the shoulder slightly exceeds the preliminary allowable shear stress used in manual sizing, this is a localized stress concentration effect and does not indicate overall shaft failure. The equivalent stress remains well below the expected yield strength of a typical steel shaft material, confirming that the design remains structurally acceptable in static loading.

# 8.3 Gear Tooth Stress Analysis and Comparison

## 8.3.1 Analytical vs Numerical Comparison

The bending stress in the critical pinion tooth was first estimated analytically using the Lewis equation, which yielded a value of approximately:

σLewis≈110.6 MPa

To validate this result, finite element analyses were performed using both 2D and 3D models of the gear tooth under the same tangential loading conditions.

## 8.3.2 2D Finite Element Results

The 2D analysis showed a maximum equivalent stress of approximately:

σ2D≈143.4 MPa

The maximum stress was clearly located at the tooth root, confirming that the dominant failure mode is bending, as assumed in the Lewis theory.

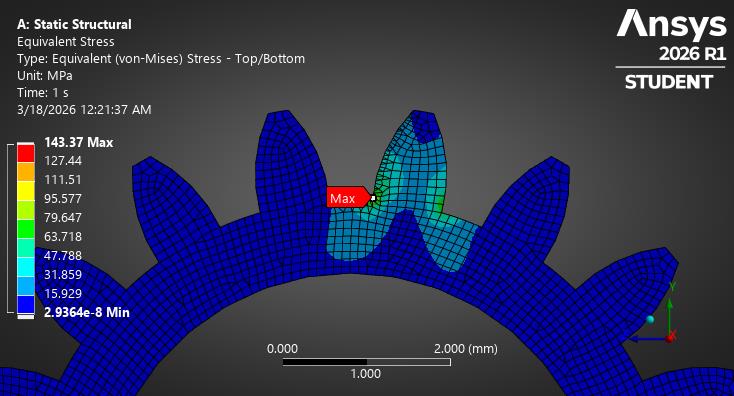
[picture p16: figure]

## 8.3.3 3D Finite Element Results

The 3D analysis resulted in a maximum equivalent stress of approximately:

σ3D≈145.2 MPa

Similar to the 2D case, the highest stress was concentrated at the tooth root region, with a very similar stress distribution pattern.

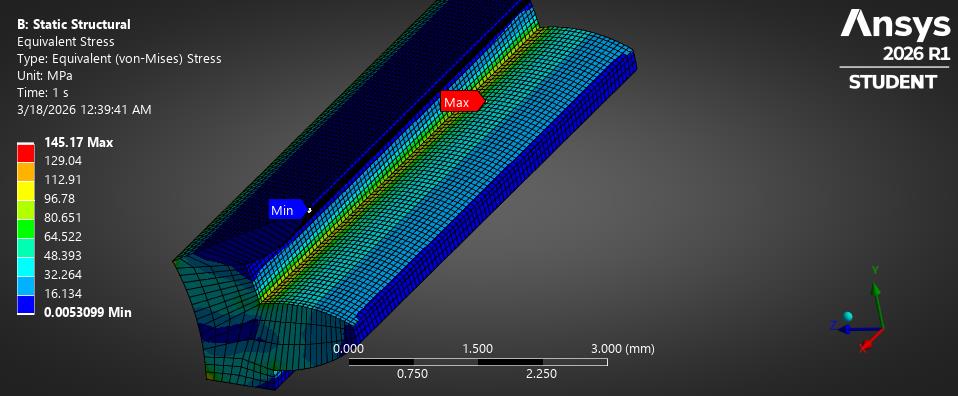
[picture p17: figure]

## 8.3.4 Discussion of Differences

The numerical results are higher than the analytical value by approximately:

- ~29% for 2D
- ~31% for 3D

This difference is expected because the Lewis equation is based on a simplified beam assumption and does not account for:

- the actual tooth geometry
- the fillet radius at the root
- local stress concentration effects

In contrast, the finite element models capture the real geometry and therefore provide a more realistic estimation of the maximum stress.

## 8.3.5 2D vs 3D Comparison

The difference between the 2D and 3D results is minimal, indicating that the stress distribution is nearly uniform across the face width of the tooth. This confirms that the 2D model is sufficient to represent the bending behavior of the gear tooth under the given loading conditions.

## 8.3.6 Conclusion

The results demonstrate good agreement between analytical and numerical approaches. While the finite element results are higher due to geometric effects, all methods consistently identify the tooth root as the critical region. The close match between 2D and 3D analyses validates the modeling approach and confirms that bending is the governing failure mechanism in the gear tooth.

# 8.4 Dog Clutch Structural Analysis

## 8.4.1 Model Description and Assumptions

A simplified finite element model of the dog clutch was developed to evaluate the local stress distribution during torque transmission. Instead of modeling the full clutch assembly, a single pair of engaging teeth was extracted and analyzed.

The model preserves the essential geometric features used in the analytical design, including:

- Mean transmission radius ≈ 8 mm
- Tooth axial width ≈ 2.5 mm
- Tooth thickness ≈ 3 mm
- Engagement depth ≈ 2.5 mm
- Chamfer angle ≈ 15°
- Presence of root fillets

To ensure numerical stability and represent the engagement condition:

- One body was fully constrained (Fixed Support)
- A force of 250 N was applied on the mating tooth
- A Remote Displacement was used to restrict motion to the loading direction
- Frictionless contact was defined between the two contacting surfaces

This setup represents a static and conservative loading case, corresponding to torque transmission through two effective dogs.

## 8.4.2 Load Justification

The applied force was derived from the design torque:

T=4 N⋅m

Using the mean transmission radius:

rm=8 mm

The total tangential force becomes:

Ft=Trm=500 N

Assuming load sharing between two active teeth:

Fdog=250 N

## 8.4.3 Analytical Stress Estimation

From the design calculations:

Bearing (contact) stress:

σbearing≈40 MPa

Shear stress:

τtheory≈33.3 MPa

These values represent average stresses, assuming uniform load distribution over the contact area.

## 8.4.4 Finite Element Results

The finite element analysis showed:

- Maximum shear stress:

τmax≈172 MPa

The stress distribution indicates that:

- The highest stresses occur at geometric discontinuities, particularly:
- Tooth root region
- Edges of the contact zone
- Chamfer transitions
- The contact region itself exhibits moderate and distributed stress levels, significantly lower than the peak values.

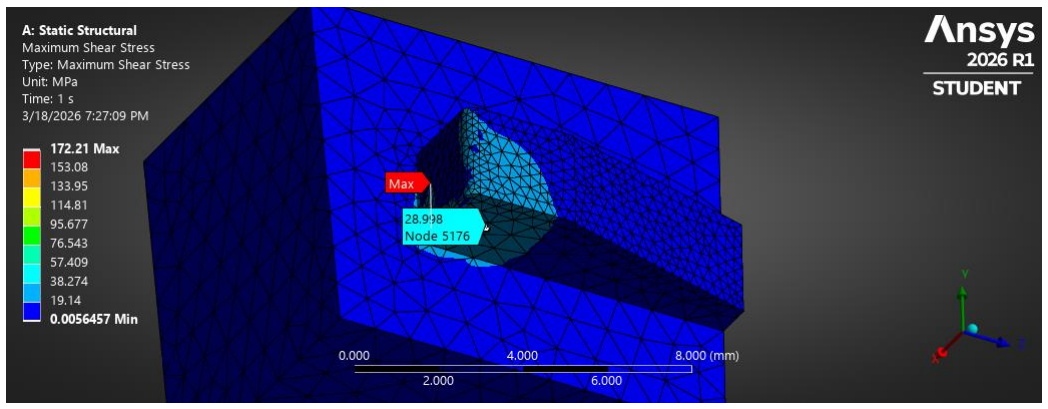
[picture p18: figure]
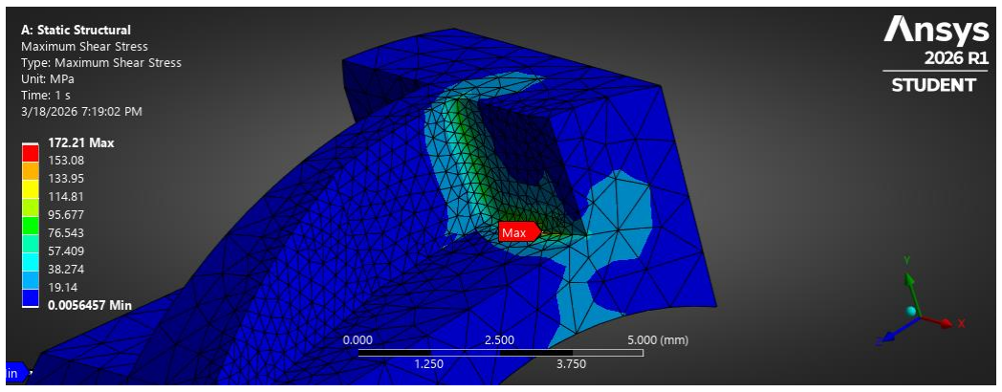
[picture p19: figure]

## 8.4.5 Comparison Between Analytical and Numerical Results

A key distinction must be made between:

- Analytical results → average stresses
- FEA results → local peak stresses

## At Contact Surfaces

At the main contact area between the two teeth:

- The stress levels are consistent with the analytical bearing stress (~40 MPa)
- The load is distributed over the surface as assumed in the design stage

This confirms that the analytical model provides a reasonable estimation of the global load transfer behavior.

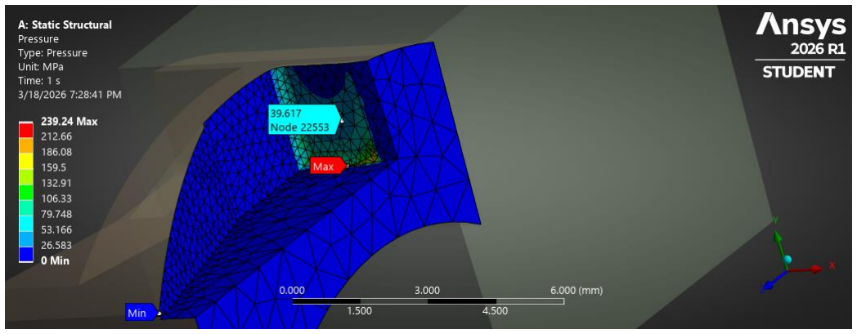
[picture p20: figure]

## At Critical Regions (Stress Concentration)

However, the finite element model reveals significantly higher stresses at localized regions:

- Tooth root
- Edges of the contact interface
- Sharp geometric transitions

These regions experience:

τlocal≫τtheory

This discrepancy arises because the analytical model:

- Assumes uniform stress distribution
- Neglects geometric discontinuities
- Does not capture stress concentration effects

Whereas the FEA model includes:

- Real geometry (fillets, chamfers)
- Local contact mechanics
- Non-uniform load distribution

## 8.4.5 Engineering Interpretation

The results indicate that:

- The overall design is acceptable from an average stress perspective
- The contact surfaces behave as expected and match analytical predictions
- However, localized stress concentrations are significant and must be considered in design evaluation

Importantly:

- The critical regions identified by FEA do not necessarily indicate immediate failure
- They highlight potential locations for:
- crack initiation
- wear concentration
- fatigue risk

## 8.4.6 Conclusion

The analytical and numerical results are in good agreement at the global level, particularly in the contact region where the load transfer occurs. However, the finite element analysis reveals important local effects that are not captured by simplified calculations.

Therefore, while the analytical model is sufficient for initial design sizing, the FEA results provide a more realistic assessment of critical stress locations, ensuring a more reliable evaluation of the clutch performance.

# - Failure Modes Analysis

To ensure a comprehensive evaluation of the proposed robotic finger system, potential failure modes were identified and analyzed based on the results obtained from analytical calculations, CAD modeling, and finite element simulations. Each subsystem presents specific failure risks depending on its function and loading conditions.

# 9.1 Failure Modes in the Finger Mechanism

The finger mechanism relies on a coupled four-bar linkage system to achieve coordinated motion between the phalanges. Although the kinematic analysis and motion simulation confirmed smooth and continuous movement, several potential failure modes may arise in practical implementation.

One of the primary risks is joint wear and clearance development. Since the mechanism depends on multiple revolute joints, repeated motion may lead to increased backlash over time, which can reduce motion accuracy and affect synchronization between phalanges.

Another possible failure mode is linkage misalignment due to manufacturing tolerances or assembly errors. Because the mechanism is highly coupled, even small deviations in link lengths or pivot locations may lead to noticeable errors in motion trajectory.

Additionally, excessive loading or unintended external forces applied at the fingertip may introduce bending stresses in the links that were not fully considered in the kinematic design stage.

# 9.2 Gearbox Failure Modes

The gearbox operates under two distinct modes (speed and force), and its components are subjected to varying torque and load conditions. Based on the analytical and numerical results, several critical failure modes can be identified.

The most significant failure risk in the gear system is gear tooth bending failure. The finite element analysis confirmed that the highest stress occurs at the tooth root, which is consistent with the assumptions of the Lewis equation. Repeated loading cycles may lead to fatigue crack initiation in this region.

Another potential failure mode is surface wear or pitting due to contact stresses between meshing gears. Although the analytical design suggests that contact stress is within acceptable limits, real-world conditions such as poor lubrication or misalignment may accelerate surface degradation.

The intermediate shaft is particularly vulnerable due to the combined effect of high torque and gear forces. Excessive loading or misalignment may lead to bending failure or increased deflection, which can affect gear meshing quality.

# 9.3 Output Shaft Failure Modes

The output shaft is the most critical component from a functional perspective, as it transmits the maximum torque and directly drives the finger mechanism.

The finite element analysis revealed that the highest stress occurs at the shoulder region due to stress concentration. Therefore, the primary failure mode is localized yielding or fatigue crack initiation at this location. While the overall stress levels are within acceptable limits, repeated loading cycles may lead to progressive damage over time.

Another possible failure mode is excessive torsional deformation if the applied load exceeds the design limit. This may affect the precision of motion transmission and lead to reduced system performance.

Additionally, since the output shaft is directly coupled to the first phalanx, any failure in
this component results in complete system failure, making it a critical | ضعف | نقطة | in the
design.

# 9.4 Dog Clutch Failure Modes

The dog clutch is responsible for switching between speed and force modes through positive mechanical engagement. While the analytical and numerical analyses confirm that the average stresses are acceptable, several failure modes are associated with its operation.

The most critical issue is impact loading during engagement. If the clutch engages while there is a speed difference between components, significant shock forces may occur, leading to edge damage or plastic deformation of the dog teeth.

Another failure mode is localized stress concentration at the tooth edges and roots, as observed in the finite element analysis. These regions may act as initiation points for cracks or wear under repeated engagement cycles.

Wear due to repeated engagement and disengagement is also a concern, particularly if the system operates frequently between modes.

# 9.5 System-Level Failure Considerations

At the system level, failure may occur due to the interaction between subsystems rather than failure of a single component.

One key risk is misalignment between the gearbox and the finger mechanism. Since the output shaft serves both as a transmission element and as a rotational joint axis, any misalignment can lead to uneven loading, increased friction, and premature wear.

Another important factor is the absence of a compliant element in the transmission system. The direct coupling design results in rigid load transfer, which may amplify shock loads and increase stress on mechanical components.

Finally, long-term fatigue behavior represents a potential failure mode that was not fully addressed in the current analysis. While the design is safe under static loading conditions, cyclic loading may lead to gradual material degradation and eventual failure.

# 9.6 Summary of Failure Modes

The main potential failure modes identified in the system include:

- Gear tooth bending fatigue at the root
- Localized yielding and fatigue at shaft shoulders
- Wear and impact damage in the dog clutch
- Joint wear and backlash in the linkage mechanism
- Misalignment-induced stress and performance degradation
- Fatigue failure under cyclic loading conditions

These failure modes highlight the importance of careful manufacturing, proper material selection, and controlled operating conditions to ensure reliable system performance.

# - Conclusion

This project presented the design, analysis, and validation of a robotic finger mechanism integrating a compact two-speed gearbox with a coupled four-bar linkage system. The proposed design successfully achieved coordinated finger motion using a single actuator, while maintaining a simple and compact mechanical architecture suitable for educational and experimental applications.

The kinematic synthesis ensured that the desired finger configurations were accurately reproduced, and the motion analysis confirmed smooth and stable dynamic behavior without undesirable discontinuities. The gearbox design effectively provided two distinct operating modes, enabling both rapid motion and sufficient torque generation to meet the functional requirements of the system.

Structural validation through analytical calculations and finite element analysis demonstrated strong agreement in the global behavior of components, while also highlighting the importance of local stress concentrations, particularly in critical regions such as shaft shoulders and gear tooth roots. The fatigue assessment further emphasized that, although the design is generally safe, localized geometric effects play a key role in long-term durability.

In addition, the analysis of failure modes and design limitations provided valuable insight into the practical challenges associated with real-world implementation, including sensitivity to alignment, manufacturing tolerances, and cyclic loading conditions. Based on these observations, several targeted design improvements were proposed to enhance system reliability, reduce stress concentrations, and improve overall performance.

In conclusion, the developed design meets the primary objectives of the project and demonstrates a successful integration of kinematic design, mechanical transmission, and structural analysis. The results confirm that the system is mechanically feasible and provides a solid foundation for further refinement, optimization, and potential physical implementation.

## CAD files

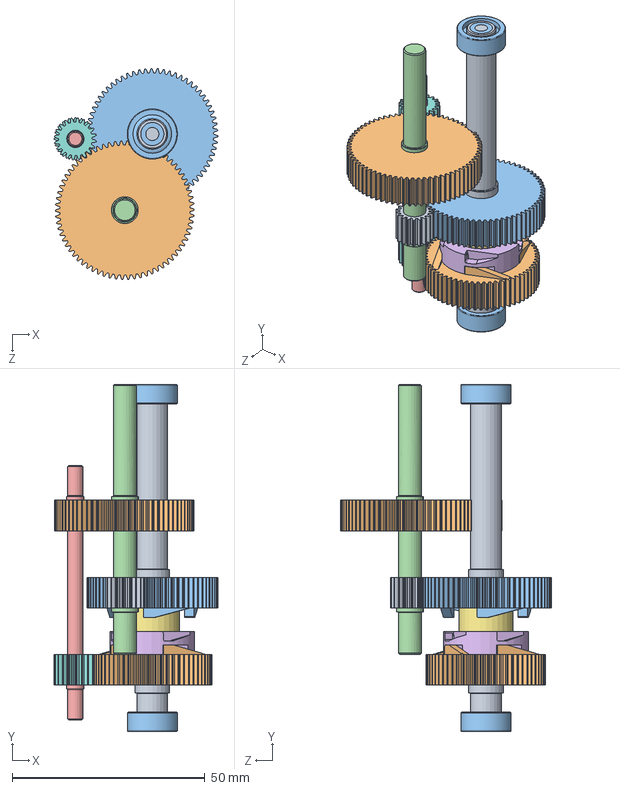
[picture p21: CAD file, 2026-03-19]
SolidWorks/GearBox/1gearbox.SLDASM
42.5 x 90.0 x 54.7 mm
OUTPUT SHAFT+
spur gear 60
spur gear 66
INTERMADATE SHAFT
INPUT SHAFT
CLUTCH SLEEVE
CLUTCH HUP
spur gear 20+ x 2
spur gear 18
spur gear 70++
radial ball bearing_68_iso x 2

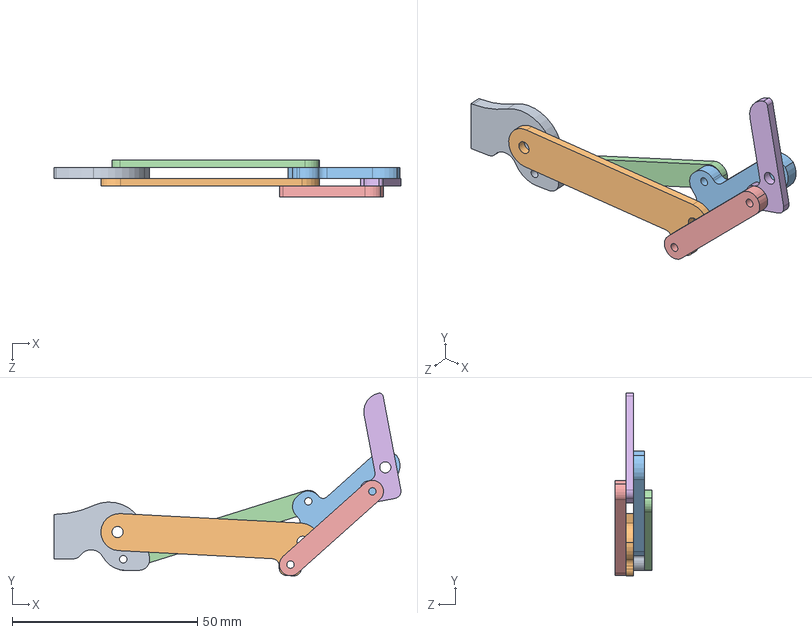
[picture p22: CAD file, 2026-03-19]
SolidWorks/FINGUR/FINGUR.SLDASM
93.6 x 49.3 x 10.0 mm
base
Phalanx_1
Phalanx_2
Link1
Link2
Phalanx_3

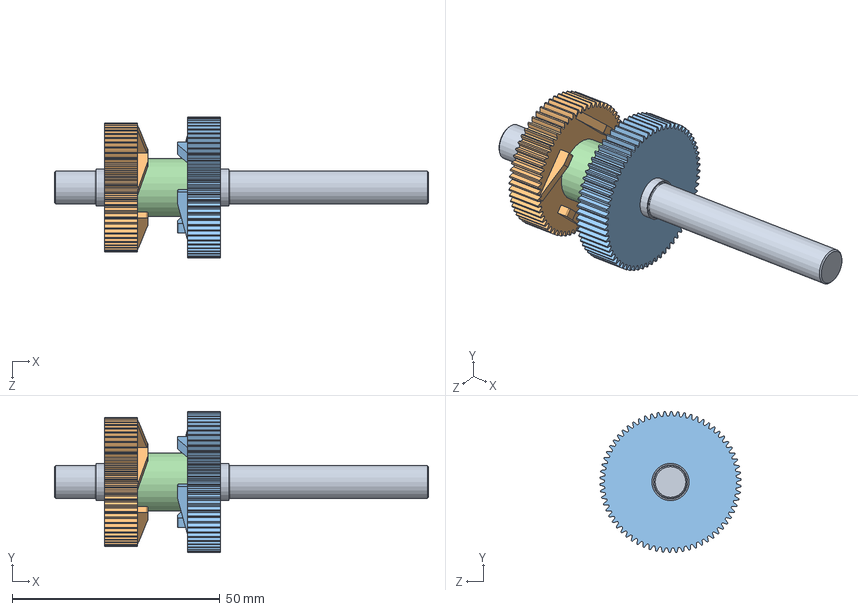
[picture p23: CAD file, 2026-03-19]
SolidWorks/GearBox/ASS OUTPUT SHAFT.SLDASM
90.0 x 34.0 x 34.0 mm
OUTPUT SHAFT+
spur gear 60
spur gear 66
CLUTCH HUP

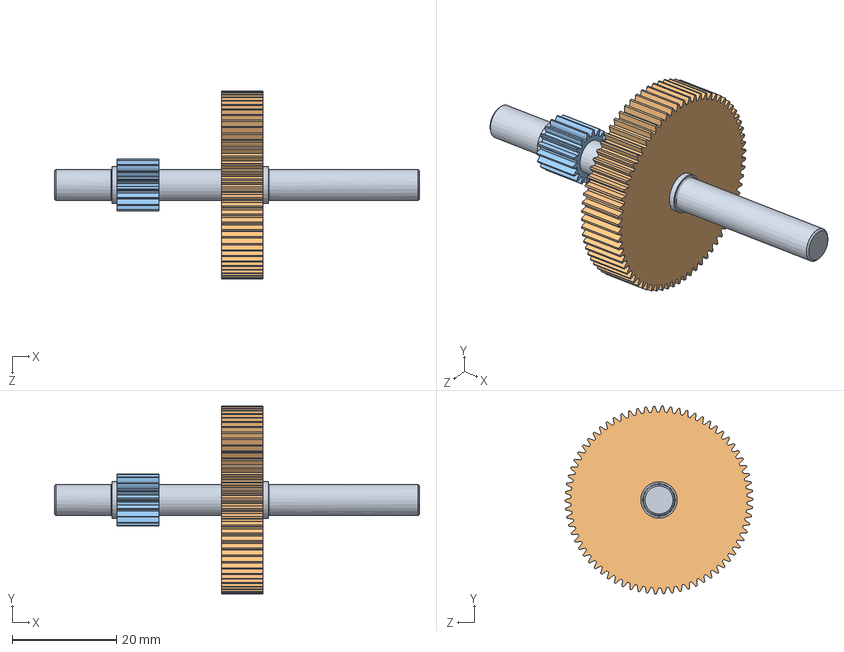
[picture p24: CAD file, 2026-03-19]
SolidWorks/GearBox/ASS INTERMADATE SHAFT.SLDASM
70.0 x 36.0 x 36.0 mm
INTERMADATE SHAFT
spur gear 70++
spur gear 18

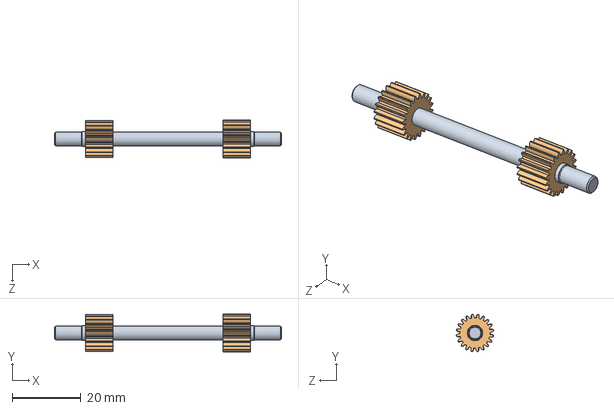
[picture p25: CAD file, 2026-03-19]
SolidWorks/GearBox/ASS INPUT SHAFT.SLDASM
66.0 x 10.9 x 10.9 mm
INPUT SHAFT
spur gear 20+ x 2

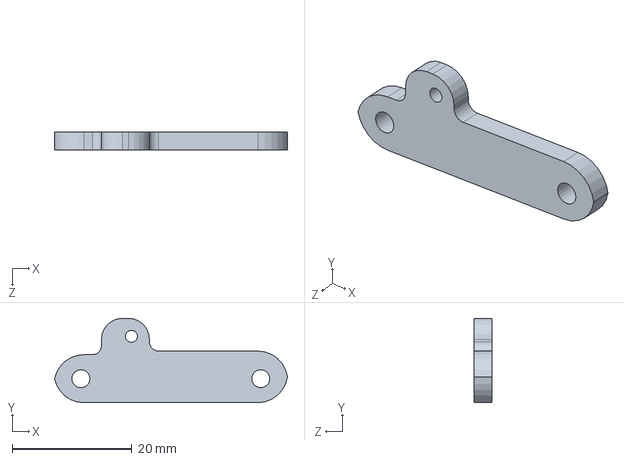
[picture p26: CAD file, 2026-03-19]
SolidWorks/FINGUR/Phalanx_2.SLDPRT
38.9 x 14.1 x 3.00 mm

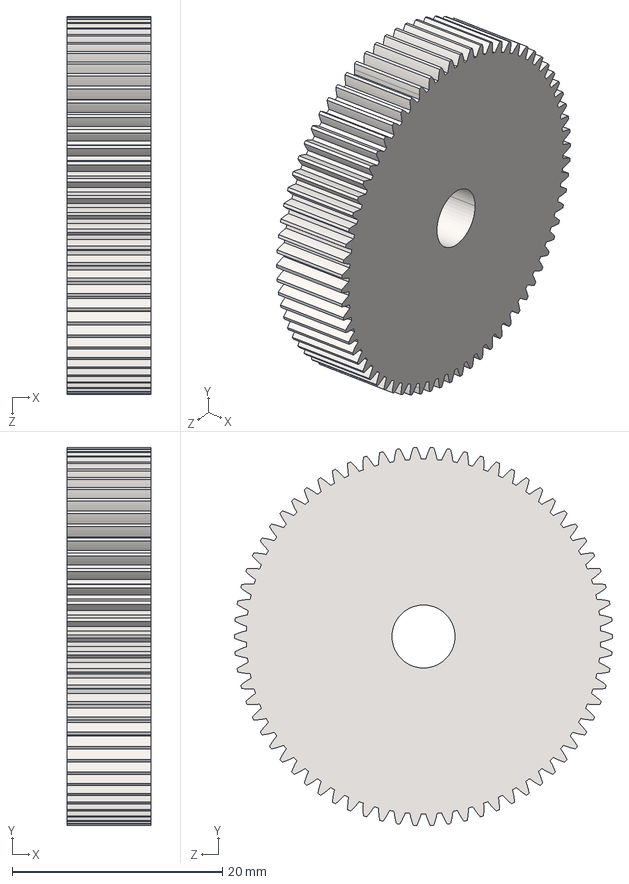
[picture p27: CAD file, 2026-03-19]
SolidWorks/GearBox/New folder/spur gear 70.STEP
8.00 x 36.0 x 36.0 mm

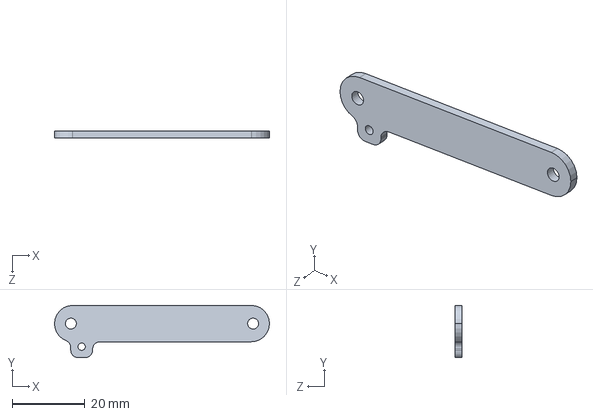
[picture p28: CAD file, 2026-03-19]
SolidWorks/FINGUR/Phalanx_1.SLDPRT
59.0 x 14.3 x 2.00 mm

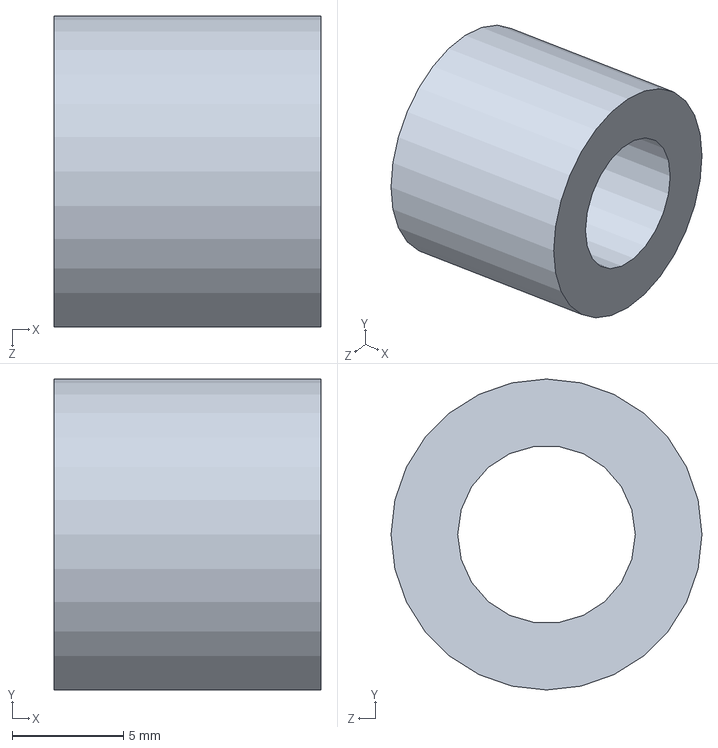
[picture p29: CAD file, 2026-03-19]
SolidWorks/GearBox/CLUTCH HUP.SLDPRT
12.0 x 14.0 x 14.0 mm

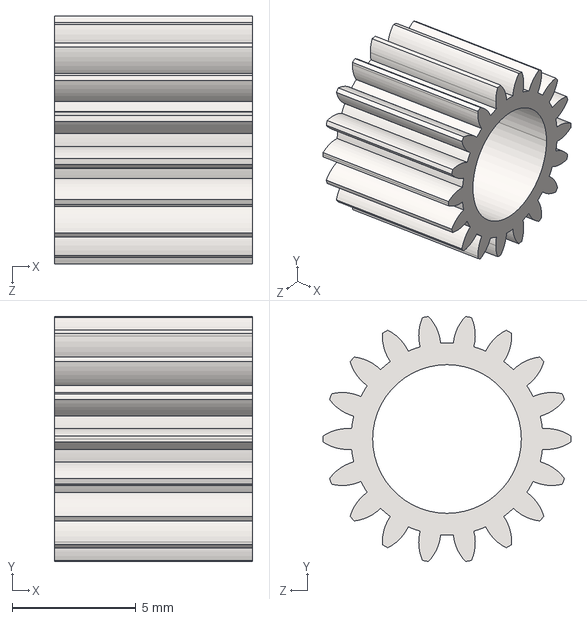
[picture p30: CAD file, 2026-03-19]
SolidWorks/GearBox/New folder/spur gear 18.STEP
8.00 x 9.89 x 10.00 mm

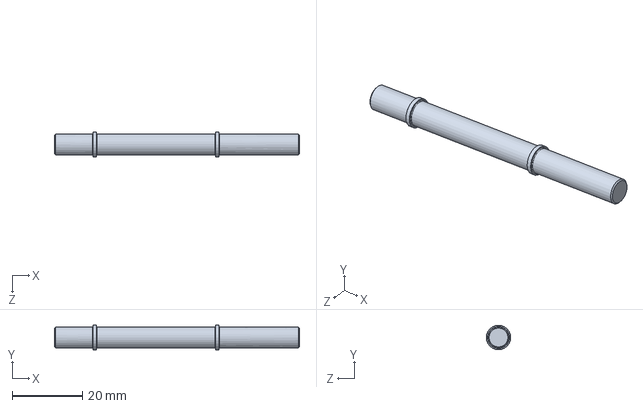
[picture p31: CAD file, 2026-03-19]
SolidWorks/GearBox/INTERMADATE SHAFT.SLDPRT
70.0 x 7.00 x 7.00 mm

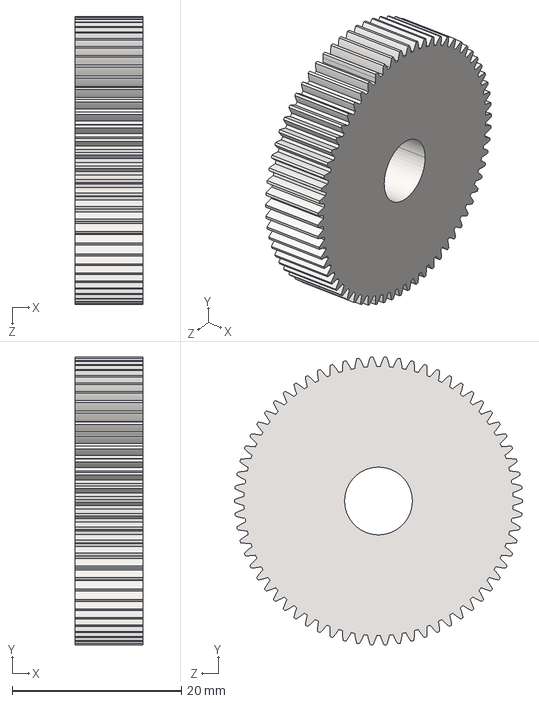
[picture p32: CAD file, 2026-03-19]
SolidWorks/GearBox/New folder/spur gear 66.STEP
8.00 x 34.0 x 34.0 mm

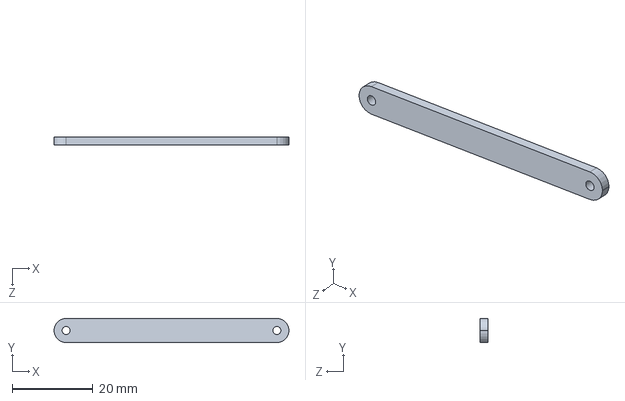
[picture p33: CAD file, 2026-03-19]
SolidWorks/FINGUR/Link1.SLDPRT
58.3 x 6.00 x 2.00 mm

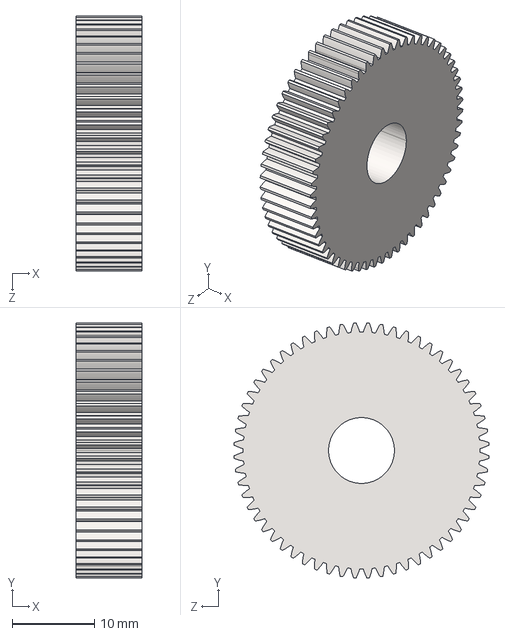
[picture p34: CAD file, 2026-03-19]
SolidWorks/GearBox/New folder/spur gear 60.STEP
8.00 x 31.0 x 31.0 mm

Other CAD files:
SolidWorks/GearBox/gearbox.SLDASM
SolidWorks/FINGUR/2D Sketch.SLDPRT
SolidWorks/GearBox/spur gear 18.SLDPRT
SolidWorks/GearBox/+PART INTERMADATE SHAFT.SLDPRT
SolidWorks/FINGUR/Link2.SLDPRT
SolidWorks/FINGUR/Phalanx_3.SLDPRT
SolidWorks/FINGUR/base.SLDPRT
SolidWorks/GearBox/2D Sketch.SLDPRT
SolidWorks/GearBox/CLUTCH SLEEVE.SLDPRT
SolidWorks/GearBox/FEA/CLUTCH.x_t
SolidWorks/GearBox/FEA/OUTPUT SHAFT+.x_t
SolidWorks/GearBox/FEA/spur gear 18.x_t
SolidWorks/GearBox/FEA/spur gear 70++.x_t
SolidWorks/GearBox/INPUT SHAFT.SLDPRT
SolidWorks/GearBox/New folder/OUTPUT SHAFT+.x_t
SolidWorks/GearBox/New folder/spur gear 20.STEP
SolidWorks/GearBox/OUTPUT SHAFT+.SLDPRT
SolidWorks/GearBox/PART INPUT SHAFT.SLDPRT
SolidWorks/GearBox/PART INTERMADATE SHAFT.SLDPRT
SolidWorks/GearBox/PRAT OUTPUT SHAFT.SLDPRT
SolidWorks/GearBox/spur gear 20+.SLDPRT
SolidWorks/GearBox/spur gear 60.SLDPRT
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
